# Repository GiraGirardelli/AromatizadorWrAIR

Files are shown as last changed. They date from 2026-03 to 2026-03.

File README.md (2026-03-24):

# Aromatizador Smart IoT (V1.0)

Um projeto open-source de um aromatizador automático inteligente, desenvolvido com foco em robustez mecânica, segurança de hardware e integração IoT em nuvem. 

O objetivo deste projeto foi solucionar as principais falhas de aromatizadores convencionais (refis proprietários caros e mecânicas frágeis) aplicando princípios de Design Mecatrônico e desenvolvendo uma infraestrutura de controle remoto completa.

## 💡 Arquitetura do Sistema

A abordagem escolhida para este projeto foi **100% Mecânica (Solid-State Control)**. Em vez de utilizar bombas hidráulicas ou diafragmas — que adicionam pontos de falha por vazamento e exigem manutenção de tubulação —, o sistema atua fisicamente sobre um frasco spray padrão de mercado (60ml/100ml) através de um mecanismo de came-seguidor.

### O Software e a Nuvem (ESP RainMaker)
O firmware foi desenvolvido utilizando o ecossistema ESP RainMaker, garantindo comunicação segura, provisionamento via Bluetooth e controle em tempo real pelo smartphone. As principais funcionalidades embarcadas incluem:
* **Controle Remoto:** Acionamento manual do mecanismo de qualquer lugar via Wi-Fi.
* **Agendamento (Scheduling):** Configuração de rotinas e timers pelo aplicativo, evitando o desperdício de essência em horários sem fluxo de pessoas.
* **Modo Noturno Automático:** Intervalo de tempo configurável onde o display OLED é desligado e qualquer acionamento mecânico é bloqueado pelo sistema.

## 🛠️ Hardware e Eletrônica

A eletrônica foi estruturada em uma perfboard com foco em segurança e modularidade, utilizando conectores JST para facilitar a manutenção.

* **Microcontrolador:** ESP32 (Responsável pelo gerenciamento do FreeRTOS, Wi-Fi e controle dos periféricos).
* **Atuador:** Servo Motor MG996R (Metal Gear). Escolhido pelo torque elevado (aprox. 10kg.cm), capaz de vencer a resistência da mola da válvula do spray com ampla margem de segurança.
* **Interface (IHM):** Display OLED I2C para feedback visual de status e conexão.
* **Proteção Elétrica:** Implementação de um capacitor eletrolítico de 1000uF na linha de 5V para suprir picos de corrente do servo motor e evitar *brownouts* (resets indesejados) no ESP32.

## ⚙️ Design Mecânico e Segurança

Toda a estrutura física, suportes e o mecanismo do came foram modelados em CAD e fabricados via impressão 3D. 
* **Design for Maintenance:** A tampa de acesso ao refil utiliza um sistema de fechamento magnético, permitindo a troca rápida do frasco.
* **Isolamento de Risco:** A eletrônica e o motor ficam fisicamente isolados em um compartimento superior, separados da área de manuseio e acima da linha do líquido, mitigando qualquer risco de curto-circuito em caso de vazamento do frasco.
* **Ajuste Fino:** O suporte do motor possui furos oblongos, permitindo a calibração da distância de ataque do came, evitando o *stall* (travamento) do motor contra o final de curso da válvula.

## 🚀 Roadmap e Próximos Passos (V2.0)

Com a V1.0 validada e em operação, o desenvolvimento atual está focado na transição do protótipo para um produto comercial escalável (V2.0). Os objetivos arquiteturais são:

1. **Custom PCB:** Substituir a perfboard e o ESP32 clássico por uma placa de circuito impresso dedicada, utilizando o módulo **ESP32-C3** (arquitetura RISC-V) para redução drástica de custos e tamanho.
3. **Sensores Inteligentes:** Integração de um sensor de presença (PIR) para acionamento condicionado à ocupação do ambiente. Além de um sistema para reconhecer a necessidade de troca da essência.

## 🖨️ Guia de Impressão 3D e Montagem

Todos os arquivos `.stl` necessários para a montagem da V1.0 estão na pasta `/3D_Files`. A maioria das peças foi otimizada para ser impressa sem suportes, mas requer atenção a alguns parâmetros específicos de fatiamento.

### Parâmetros Gerais Recomendados
* **Material:** PLA ou PETG (PETG recomendado para maior resistência térmica próxima ao motor).
* **Altura da Camada:** 0.20 mm.
* **Infill (Preenchimento):** 15% a 20% (Gyroid).
* **Orientação:** Respeitar a orientação original dos arquivos STL para garantir a resistência mecânica das camadas.

### ⚠️ Peças Críticas e Pausas de Impressão (M125)

**1. O Came (came_motor.stl)**
* Esta peça sofre alto estresse mecânico. É mandatório fatiar com **100% de Infill** (ou aumentar o número de paredes/perímetros para 6+) para garantir que o eixo do servo não espane o plástico.

**2. Base e Tampa Magnética (base_case.stl / tampa_case.stl)**
* Para embutir os ímãs de neodímio (tamanho 4mm x 2mm) de forma invisível, você deve configurar uma **pausa na impressão** no seu fatiador.
* **Carcaça princial:** Inserir pausa na camada **240** (ou na altura X.X mm). Coloque os ímãs, certifique-se de que estão rentes ao plástico e retome a impressão.
* **Pausa nas Tampas:** Inserir pausa na camada **15**. **Atenção à polaridade** dos ímãs antes de inserir, para garantir que a tampa seja atraída e não repelida pela base!
* * **Dica:**  Recomendo o uso de um pouco de cola instatânea (cianoacrilato) nos furos para os imãs para não ter problemas durante o resto da impressão

---
* Sinta-se livre para analisar o código, utilizar os arquivos STL e propor melhorias para as próximas versões.*

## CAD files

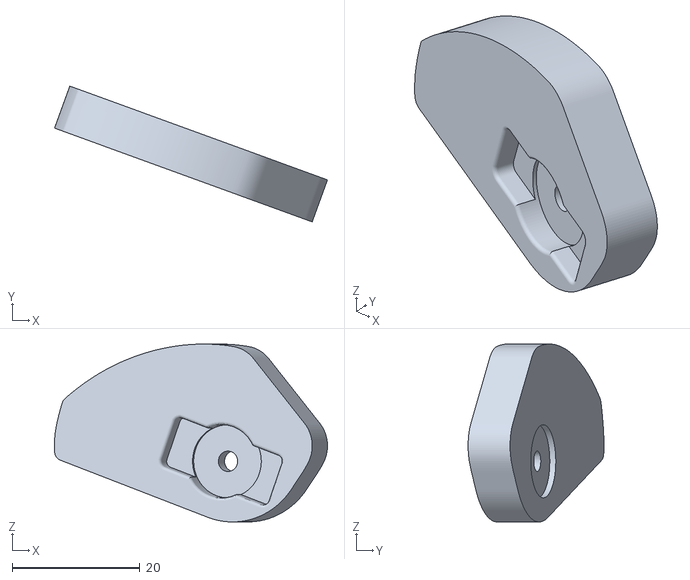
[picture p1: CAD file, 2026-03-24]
3D_files/came 2.0.stl
42.8 x 21.3 x 27.9

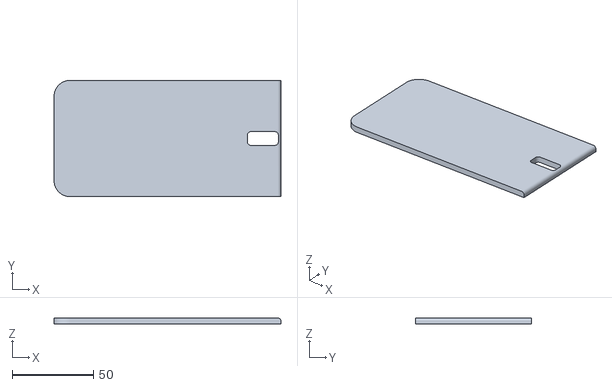
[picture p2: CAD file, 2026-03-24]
3D_files/tampa spray.stl
139.7 x 71.6 x 3.80

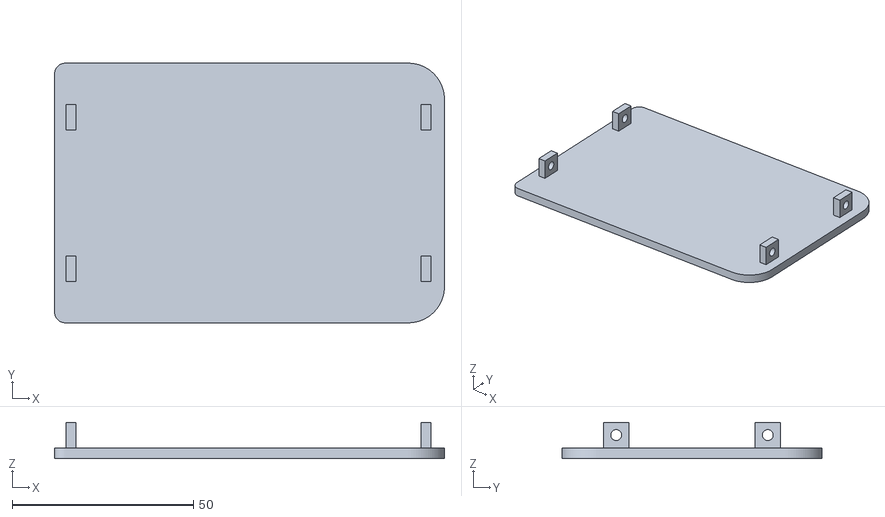
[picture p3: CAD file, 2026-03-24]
3D_files/tampa circuito.stl
107.6 x 71.6 x 10.0

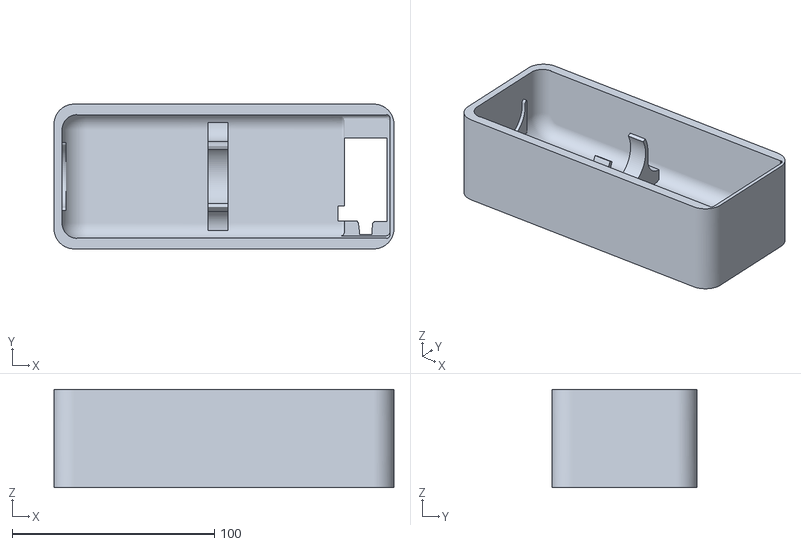
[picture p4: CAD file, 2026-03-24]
3D_files/carcaca principal.stl
168.2 x 71.6 x 48.5

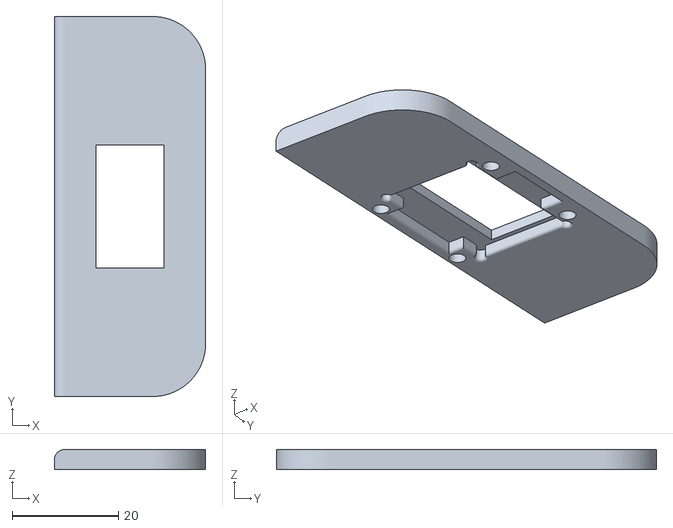
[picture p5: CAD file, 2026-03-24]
3D_files/tampa display.stl
28.5 x 71.6 x 3.80

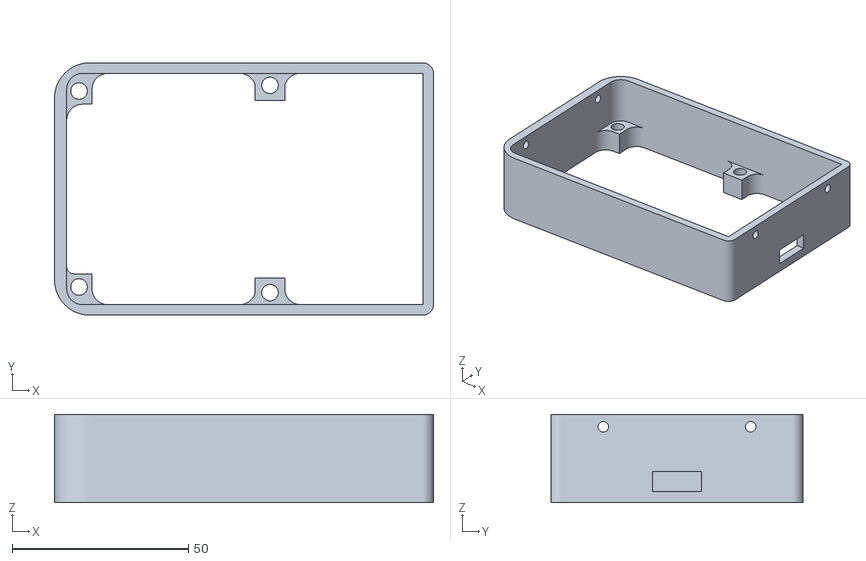
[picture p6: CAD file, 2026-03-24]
3D_files/caixa circuito.stl
107.6 x 71.6 x 25.0

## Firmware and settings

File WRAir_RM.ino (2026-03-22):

#include "RMaker.h"
#include "WiFi.h"
#include "WiFiProv.h"
#include "AppInsights.h"
#include <ESP32Servo.h>
#include "time.h"

// --- DISPLAY ---
#include <Wire.h>
#include <Adafruit_GFX.h>
#include <Adafruit_SSD1306.h>

// Prevenção de Brownout
#include "soc/soc.h"
#include "soc/rtc_cntl_reg.h"

#define SCREEN_WIDTH 128
#define SCREEN_HEIGHT 64
Adafruit_SSD1306 display(SCREEN_WIDTH, SCREEN_HEIGHT, &Wire, -1);

// --- CONFIGURAÇÕES ---
#define DEFAULT_POWER_MODE false 
const char *service_name = "PROV_aromatizador";
const char *pop = "123456"; 

// Mecânica
#define PINO_SERVO 18
#define ANGULO_REPOUSO 0   
int angulo_aperto = 60; 
#define TEMPO_APERTO   1000 
int qtd_disparos = 1; 

char texto_ultimo_disparo[10] = "--:--";

// Controles
unsigned long momento_liberacao = 0; 
unsigned long ultimoUpdate = 0;
#define TEMPO_COOLDOWN 1000 
bool dnd_ativo = false;    
float dnd_inicio = 22.0;   
float dnd_fim = 7.0;   
bool tela_ligada = true;
bool sincronizar_tela_app = false;

// Trava de segurança do Display
bool sessao_provisionamento_encerrada = false; 
unsigned long timestamp_fim_prov = 0;

Servo meuServo;

// GPIO
#if CONFIG_IDF_TARGET_ESP32C3
static int gpio_0 = 9;
static int gpio_switch = 7;
static int gpio_reset = 4;
#else
static int gpio_0 = 0;
static int gpio_switch = 2;
static int gpio_reset = 4;
#endif

static Switch *my_switch = NULL;

void getHoraAtual(char *buffer, size_t tamanho) {
    struct tm timeinfo;
    if(!getLocalTime(&timeinfo, 0)) {
        strncpy(buffer, "--:--", tamanho);
        return;
    }
    strftime(buffer, tamanho, "%H:%M", &timeinfo);
}

// --- FUNÇÃO DE DESENHO ---
void atualizarTela(String titulo, String rodape = "", bool limpar = true) {
    // 1. SEGURANÇA
    if (!sessao_provisionamento_encerrada && titulo != "SETUP") return;

    if (!tela_ligada) return;

    if (limpar) display.clearDisplay();
    display.setTextColor(SSD1306_WHITE);

    // --- CABEÇALHO ---
    display.setTextSize(1);
    display.setCursor(0, 0);
    display.print(F("WrAIR")); 
    display.setCursor(110, 0); 
    if (WiFi.status() == WL_CONNECTED) display.print(F("(W)"));
    else display.print(F("(!)"));
    display.drawLine(0, 10, 128, 10, SSD1306_WHITE);

    // --- LÓGICA ---
    if (titulo == "ONLINE") {
        // A própria função busca a hora atual
        char horaBuff[10];
        getHoraAtual(horaBuff, sizeof(horaBuff));

        // Hora Grande (Centro)
        display.setTextSize(3);
        // Centralização aproximada (Tam 3 = ~18px largura)
        int len = strlen(horaBuff);
        int x_hora = (128 - (len * 18)) / 2;
        if(x_hora < 0) x_hora = 0;
        
        display.setCursor(x_hora, 22);
        display.print(horaBuff);

        // Rodapé (Último Disparo - Variável Global)
        display.setTextSize(1);
        display.setCursor(0, 54);
        display.print(F("Ultimo: "));
        display.print(texto_ultimo_disparo);
    }
    else {
        // AÇÃO (Spray, etc)
        display.setTextSize(2);
        int x_titulo = (128 - (titulo.length() * 12)) / 2;
        if(x_titulo < 0) x_titulo = 0;

        display.setCursor(x_titulo, 25);
        display.print(titulo);

        display.setTextSize(1);
        display.setCursor(0, 54);
        display.print(rodape);
    }

    display.display();
}


// Tela Estática de Boot
void mostrarTelaPareamento() {
    display.clearDisplay();
    display.setTextColor(SSD1306_WHITE);
    
    display.setTextSize(1);
    display.setCursor(0, 0); 
    display.println("MODO PAREAMENTO");
    display.drawLine(0, 10, 128, 10, SSD1306_WHITE);

    display.setCursor(0, 20);
    display.println("Abra App RainMaker");
    display.setCursor(0, 32);
    display.println("No QRCode > BLE'");

    display.setTextSize(2);
    display.setCursor(0, 48);
    display.print("POP:"); display.println(pop); 

    display.display();
}


void sysProvEvent(arduino_event_t *sys_event)
{
    switch (sys_event->event_id) {
    case ARDUINO_EVENT_PROV_START:
#if CONFIG_IDF_TARGET_ESP32S2
        Serial.printf("\nSoftAP Provisioning\n");
        printQR(service_name, pop, "softap");
#else
        Serial.printf("\nBLE Provisioning\n");
        printQR(service_name, pop, "ble");
#endif
        break;
        
    case ARDUINO_EVENT_PROV_CRED_SUCCESS:
        // Deixa o Bluetooth ligado para o celular receber a confirmação de sucesso.
        Serial.println("Credenciais recebidas! Conectando...");
        break;

    case ARDUINO_EVENT_PROV_END:
        // Este evento acontece sozinho quando o App RainMaker termina o trabalho.
        Serial.println("\n--- FIM DO PROVISIONAMENTO ---");
        sessao_provisionamento_encerrada = true;
        timestamp_fim_prov = millis();
        break;

    case ARDUINO_EVENT_WIFI_STA_GOT_IP:
        Serial.println("IP Obtido! Conectado ao Wi-Fi.");
        sessao_provisionamento_encerrada = true;
        break;
        
    default:;
    }
}

bool verificarPodeDisparar() {
    if (!dnd_ativo) return true; 
    struct tm timeinfo;
    if(!getLocalTime(&timeinfo, 0)) return true; 

    int minutos_agora = (timeinfo.tm_hour * 60) + timeinfo.tm_min;
    int minutos_inicio = dnd_inicio * 60; 
    int minutos_fim = dnd_fim * 60;       

    bool dentro = false;
    if (minutos_inicio < minutos_fim) {
        if (minutos_agora >= minutos_inicio && minutos_agora < minutos_fim) dentro = true;
    } else {
        if (minutos_agora >= minutos_inicio || minutos_agora < minutos_fim) dentro = true;
    }

    if (dentro) {
        if (sessao_provisionamento_encerrada) { 
            atualizarTela("BLOQUEADO", "Modo DND Ativo");
            delay(2000);
            
            char horaBuff[10]; // Cria variável temporária
            getHoraAtual(horaBuff, sizeof(horaBuff)); // Preenche a hora nela
            atualizarTela("ONLINE", horaBuff); // Usa a variável
        }
        return false; 
    }
    return true; 
}

void write_callback(Device *device, Param *param, const param_val_t val, void *priv_data, write_ctx_t *ctx)
{
    const char *param_name = param->getParamName();

    if (strcmp(param_name, "Power") == 0) {
        if (val.val.b == true) {

            if (!verificarPodeDisparar()) {
                param->updateAndReport(value(false));
                return;
            }
            
            if (millis() < momento_liberacao) {
                if(sessao_provisionamento_encerrada) {
                    atualizarTela("COOLDOWN", "Aguarde...");
                    delay(1000);
                    char horaTemp[10];
                    getHoraAtual(horaTemp, sizeof(horaTemp));
                    atualizarTela("ONLINE", horaTemp);
                }
                param->updateAndReport(value(false)); 
                return; 
            }

            digitalWrite(gpio_switch, HIGH);
            
            if(sessao_provisionamento_encerrada) atualizarTela("ATUANDO", "Spray...");

            for (int i = 1; i <= qtd_disparos; i++) {
                if(sessao_provisionamento_encerrada) {
                     String status = "SPRAY " + String(i) + "/" + String(qtd_disparos);
                     atualizarTela(status, "Em progresso...");
                }

                meuServo.attach(PINO_SERVO);
                meuServo.write(angulo_aperto); 
                delay(TEMPO_APERTO); 

                meuServo.write(ANGULO_REPOUSO);
                
                if (i < qtd_disparos) {
                    delay(1500); 
                    meuServo.detach(); 
                } else {
                    delay(600);
                    meuServo.detach(); 
                }
            }
            // --- ATUALIZA A HORA DO ULTIMO DISPARO ---
            getHoraAtual(texto_ultimo_disparo, sizeof(texto_ultimo_disparo));

            if (my_switch) {
                 struct tm timeinfo;
                 if(getLocalTime(&timeinfo, 0)){
                      char timeStringBuff[50];
                      strftime(timeStringBuff, sizeof(timeStringBuff), "%d/%m as %H:%M", &timeinfo);
                      my_switch->updateAndReportParam("Ultimo Disparo", timeStringBuff);
                 }
            }

            digitalWrite(gpio_switch, LOW);
            param->updateAndReport(value(false));
            momento_liberacao = millis() + TEMPO_COOLDOWN;
            
            getHoraAtual(texto_ultimo_disparo, sizeof(texto_ultimo_disparo));

            if(sessao_provisionamento_encerrada) {
                char horaTemp[10];
                getHoraAtual(horaTemp, sizeof(horaTemp));
                atualizarTela("ONLINE", horaTemp);
            }

        } else {
            digitalWrite(gpio_switch, LOW);
            param->updateAndReport(val);
        }
    }
    else if (strcmp(param_name, "Tela OLED") == 0) {
        tela_ligada = val.val.b;
        if (tela_ligada) {
            display.ssd1306_command(SSD1306_DISPLAYON);
            // Força atualizar a tela na hora para não ficar preta esperando 1 minuto
            if(sessao_provisionamento_encerrada) {
                char horaTemp[10];
                getHoraAtual(horaTemp, sizeof(horaTemp));
                atualizarTela("ONLINE", horaTemp);
            }
        } else {
            // Limpa a memória antes de apagar a tela fisicamente
            display.clearDisplay();
            display.display();
            display.ssd1306_command(SSD1306_DISPLAYOFF);
        }
        param->updateAndReport(val);
    }
    else if (strcmp(param_name, "Qtd Sprays") == 0) {
        qtd_disparos = val.val.i;
        param->updateAndReport(val);
    }
    else if (strcmp(param_name, "Modo Noturno") == 0) {
        dnd_ativo = val.val.b;
        ultimoUpdate = 0;
        param->updateAndReport(val);
    }
    else if (strcmp(param_name, "DND Inicio") == 0) {
        dnd_inicio = val.val.f; 
        ultimoUpdate = 0;
        param->updateAndReport(val);
    }
    else if (strcmp(param_name, "DND Fim") == 0) {
        dnd_fim = val.val.f;   
        ultimoUpdate = 0; 
        param->updateAndReport(val);
    }
}

void setup()
{
    WRITE_PERI_REG(RTC_CNTL_BROWN_OUT_REG, 0);
    Serial.begin(115200);
    configTzTime("<-03>3", "pool.ntp.org", "time.nist.gov");

    // DISPLAY INICIAL - BLOQUEADO
    if(!display.begin(SSD1306_SWITCHCAPVCC, 0x3C)) { 
        Serial.println(F("Erro OLED"));
    }
    mostrarTelaPareamento(); 

    pinMode(gpio_reset, INPUT_PULLUP);
    pinMode(gpio_switch, OUTPUT);
    digitalWrite(gpio_switch, DEFAULT_POWER_MODE);

    ESP32PWM::allocateTimer(0);
    meuServo.setPeriodHertz(50);
    meuServo.attach(PINO_SERVO);
    meuServo.write(ANGULO_REPOUSO); 
    delay(500);
    meuServo.detach();

    Node my_node;
    my_node = RMaker.initNode("ESP RainMaker Node");

    my_switch = new Switch("Switch", &gpio_switch);
    if (!my_switch) return;
    
    my_switch->addParam(Param("Ultimo Disparo", "esp.param.text", value("---"), PROP_FLAG_READ));

    Param tela_sw("Tela OLED", ESP_RMAKER_PARAM_POWER, value(tela_ligada), PROP_FLAG_READ | PROP_FLAG_WRITE);
    tela_sw.addUIType(ESP_RMAKER_UI_TOGGLE);
    my_switch->addParam(tela_sw);

    Param qtd("Qtd Sprays", ESP_RMAKER_PARAM_RANGE, value(qtd_disparos), PROP_FLAG_READ | PROP_FLAG_WRITE);
    qtd.addBounds(value(1), value(5), value(1)); 
    qtd.addUIType(ESP_RMAKER_UI_SLIDER);
    my_switch->addParam(qtd);

    Param dnd_sw("Modo Noturno", ESP_RMAKER_PARAM_POWER, value(dnd_ativo), PROP_FLAG_READ | PROP_FLAG_WRITE);
    dnd_sw.addUIType(ESP_RMAKER_UI_TOGGLE);
    my_switch->addParam(dnd_sw);

    Param dnd_ini("DND Inicio", ESP_RMAKER_PARAM_RANGE, value(dnd_inicio), PROP_FLAG_READ | PROP_FLAG_WRITE);
    dnd_ini.addBounds(value(0.0f), value(24.0f), value(0.5f)); 
    dnd_ini.addUIType(ESP_RMAKER_UI_SLIDER);
    my_switch->addParam(dnd_ini);

    Param dnd_end("DND Fim", ESP_RMAKER_PARAM_RANGE, value(dnd_fim), PROP_FLAG_READ | PROP_FLAG_WRITE);
    dnd_end.addBounds(value(0.0f), value(24.0f), value(0.5f)); 
    dnd_end.addUIType(ESP_RMAKER_UI_SLIDER);
    my_switch->addParam(dnd_end);

    my_switch->addCb(write_callback);
    my_node.addDevice(*my_switch);

    RMaker.enableOTA(OTA_USING_TOPICS);
    RMaker.enableTZService();
    RMaker.enableSchedule();
    RMaker.enableScenes();
    initAppInsights();
    RMaker.enableSystemService(SYSTEM_SERV_FLAGS_ALL, 0, 0, 0);

    RMaker.start();

    // Reset estado
    my_switch->updateAndReportParam(ESP_RMAKER_DEF_POWER_NAME, false);

    WiFi.onEvent(sysProvEvent);
#if CONFIG_IDF_TARGET_ESP32S2
    WiFiProv.beginProvision(WIFI_PROV_SCHEME_SOFTAP, WIFI_PROV_SCHEME_HANDLER_NONE, WIFI_PROV_SECURITY_1, pop, service_name);
#else
    WiFiProv.beginProvision(WIFI_PROV_SCHEME_BLE, WIFI_PROV_SCHEME_HANDLER_FREE_BTDM, WIFI_PROV_SECURITY_1, pop, service_name);
#endif
}

void loop()
{
    static bool status_noturno_anterior = false; 
    static bool primeira_leitura_feita = false; 

    // SÓ RODA SE TIVER CONECTADO E CONFIGURADO
    if (sessao_provisionamento_encerrada && WiFi.status() == WL_CONNECTED) {
        
        // --- ATUALIZA O APP SE A AUTOMAÇÃO DESLIGAR A TELA ---
        if (sincronizar_tela_app) {
            if (my_switch) my_switch->updateAndReportParam("Tela OLED", tela_ligada);
            sincronizar_tela_app = false;
        }

        // --- 1. TRAVA DE SEGURANÇA ---
        if (timestamp_fim_prov != 0) {
            if (millis() - timestamp_fim_prov < 3000) {
                return; 
            } else {
                timestamp_fim_prov = 0; 
                ultimoUpdate = 0; 
            }
        }

        // --- 2. INTERVALO E AUTOMAÇÃO DA TELA ---
        long intervalo = 60000; 
        
        if (ultimoUpdate == 0 || millis() - ultimoUpdate > intervalo) { 
            struct tm timeinfo;
            
            // Tenta pegar a hora de forma segura 
            bool hora_valida = getLocalTime(&timeinfo, 0); 
            
            if(!hora_valida){
                intervalo = 2000; 
            } else {
                intervalo = 60000;

                // --- AUTOMAÇÃO DA TELA MODO NOTURNO ---
                bool deve_estar_desligada = false;
                
                // Só verifica os horários se o botão do Modo Noturno estiver ligado no app
                if (dnd_ativo) {
                    int minutos_agora = (timeinfo.tm_hour * 60) + timeinfo.tm_min;
                    int minutos_inicio = dnd_inicio * 60;
                    int minutos_fim = dnd_fim * 60;

                    if (minutos_inicio < minutos_fim) {
                        if (minutos_agora >= minutos_inicio && minutos_agora < minutos_fim) deve_estar_desligada = true;
                    } else {
                        if (minutos_agora >= minutos_inicio || minutos_agora < minutos_fim) deve_estar_desligada = true;
                    }
                }

                // Só executa a ação se o status tiver mudado OU se for a leitura inicial do boot
                if (deve_estar_desligada != status_noturno_anterior || !primeira_leitura_feita) {
                    status_noturno_anterior = deve_estar_desligada; 
                    
                    if (deve_estar_desligada) { 
                        // Entrou no horário DND: Limpa a memória e desliga fisicamente
                        tela_ligada = false;
                        display.clearDisplay();
                        display.display();
                        display.ssd1306_command(SSD1306_DISPLAYOFF);
                    } else { 
                        // Saiu do horário DND (ou o DND foi desativado): Religa a tela
                        tela_ligada = true;
                        display.ssd1306_command(SSD1306_DISPLAYON);
                        
                        // Força o desenho imediato para a tela não ficar preta esperando 1 minuto
                        char horaTemp[10];
                        getHoraAtual(horaTemp, sizeof(horaTemp));
                        atualizarTela("ONLINE", horaTemp);
                    }
                    
                    // Sincroniza o botão "Tela OLED" no app do celular
                    if (primeira_leitura_feita) {
                        sincronizar_tela_app = true; 
                    }
                    primeira_leitura_feita = true;
                }
            }

            atualizarTela("ONLINE");
            ultimoUpdate = millis();
        }
    }
    // --- LÓGICA DO BOTÃO DE RESET (CRUA E DIRETA) ---
    if (digitalRead(gpio_reset) == LOW) {
        delay(200); // Filtro anti-ruído rápido
        
        if (digitalRead(gpio_reset) == LOW) { // Confirma que é um toque real
            
            // Só executa o reset do Wi-Fi e pronto
            RMakerWiFiReset(2); 
            
            // Trava o código aqui e espera a placa reiniciar sozinha
            while(true) delay(100); 
        }
    }
    delay(50); // Dá um fôlego para o processador
}

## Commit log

2026-03-07 Adjust servo angle and update display logic
2026-03-24 Add 3D printing guide and critical part instructions
    Added 3D printing and assembly guide with recommended parameters and critical parts.
2026-03-24 Revise magnet embedding instructions in README
    Updated instructions for embedding neodymium magnets in the base and caps, including specific layer numbers for pauses during printing.
2026-04-16 configurando o codigo para a V2
    As mudancas principais sao em funcaoi do hardware e de alguns ajustes no modelo 3d, a principio nada muito grande., em breve seguiremos com mudancas mais interessantes.
